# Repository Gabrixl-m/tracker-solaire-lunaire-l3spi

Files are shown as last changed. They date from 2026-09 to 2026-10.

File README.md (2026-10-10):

# Tracker solaire lunaire deux axes — maquette 3D à l'échelle 1:1

Maquette CAO d'un tracker solaire destiné à la surface de la Lune. Elle comprend :
* un trépied déployable ;
* une **tête rotative à vis sans fin** (azimut + élévation, deux petits moteurs pas à pas
  pilotés par un ESP32) ;
* **le panneau photovoltaïque de 356 × 253 × 30 mm**, avec son **capteur solaire** (4
  photodiodes sous une croix d'ombre, § 3) ;
* un faisceau de câbles et une unité de contrôle posée au sol.

Les deux vis sans fin sont **irréversibles** : la tête tient le panneau dans toutes les
positions **moteurs coupés**, sans contrepoids, sur Terre comme sur la Lune.
Toutes les cotes sont en **millimètres, à taille réelle**.

| Vue d'ensemble (panneau à 40°) | Tête rotative à vis sans fin |
|---|---|
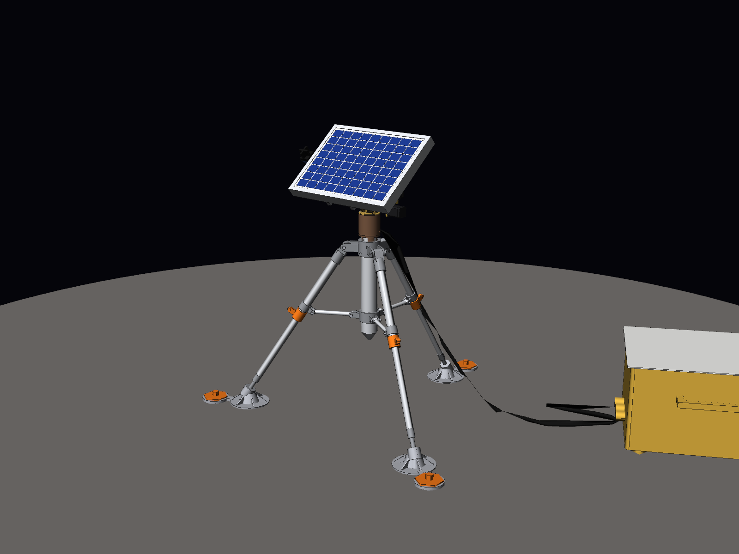
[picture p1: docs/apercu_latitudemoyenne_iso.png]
Vue d'ensemble
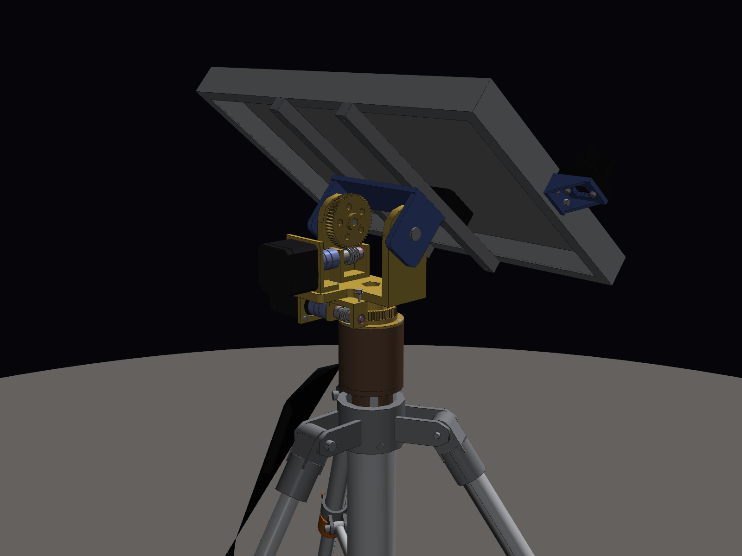
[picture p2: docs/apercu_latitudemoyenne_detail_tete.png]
Tête à vis sans fin
|  |  |
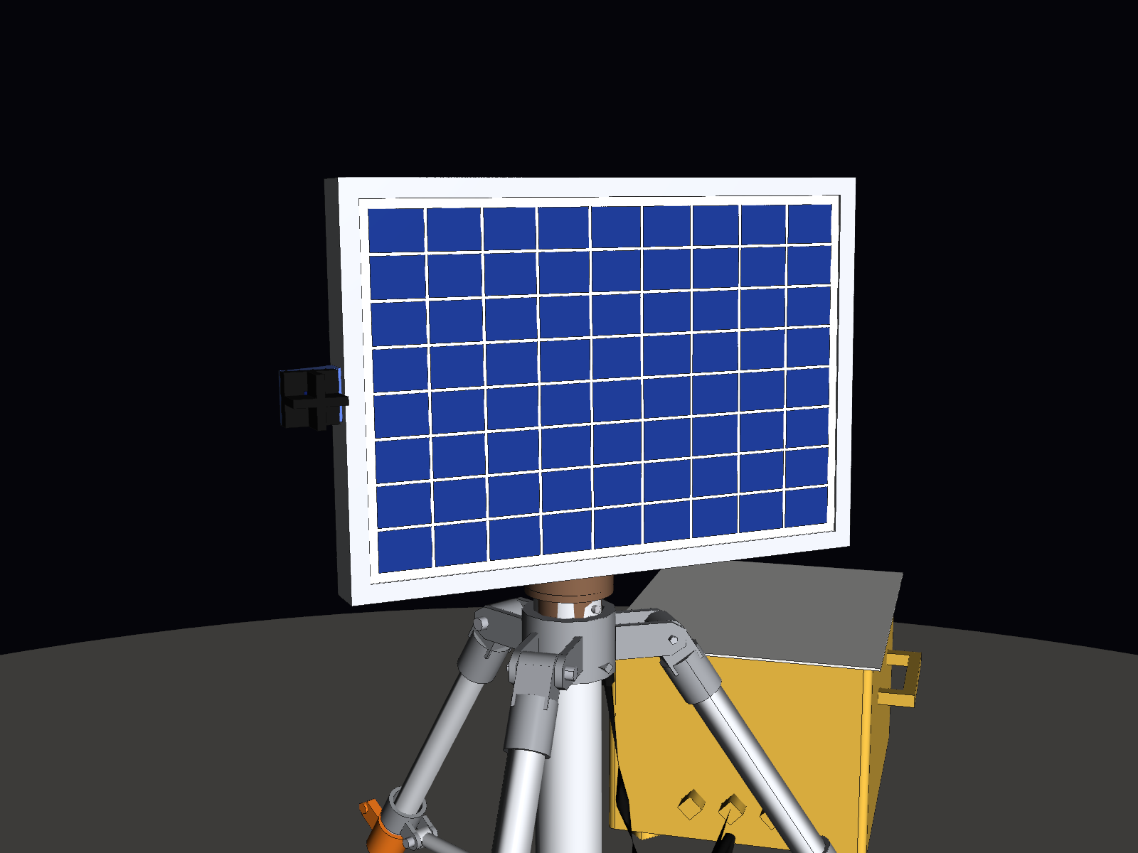
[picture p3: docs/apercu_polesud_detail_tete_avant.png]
Pôle Sud
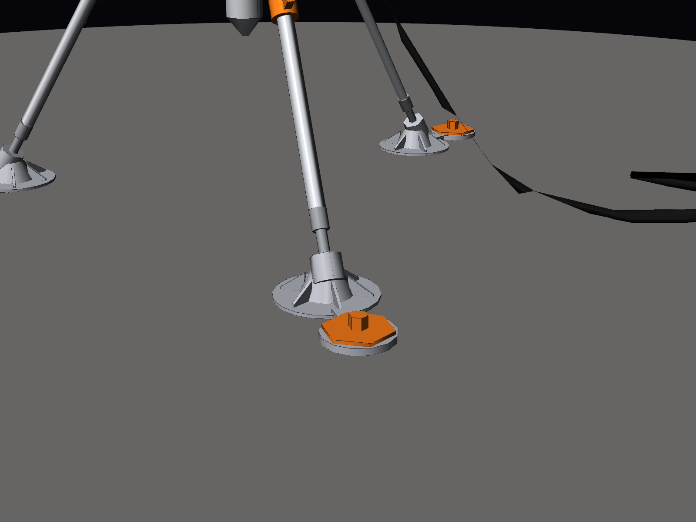
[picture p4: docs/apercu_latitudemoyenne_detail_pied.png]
Pied et vis d'ancrage
|  |  |

Ce document a trois parties, suivies de la bibliographie :
* **Partie A — Le tracker lunaire (cas réel)** : tête rotative, panneau, capteur solaire,
  conditions lunaires, trépied, matériaux et vérifications (§ 1 à 10) ;
* **Partie B — La démonstration sur Terre** : la même tête imprimée en PETG et posée sur un
  trépied photo, avec ce qui change par rapport au cas réel et tout ce qu'il faut pour la
  fabriquer (§ 11 à 19) ;
* **Partie C — Fichiers, scripts, régénération et licence** (§ 20 à 23) ;
* **Bibliographie**.

Organisation du dépôt :

```
CAO/Cas_Reel/          fichiers STEP du tracker lunaire : assemblages et pièces seules
CAO/Demo_Terre_PETG/   démonstration sur Terre : pièces à imprimer (STL + STEP) et assemblages
docs/                  rendus, images annotées, bilan de masse, optimisation des jambes
scripts/               scripts Python qui génèrent la CAO, les contrôles et les rendus
LISTE_ACHATS.md        liste d'achats de la démonstration sur Terre
requirements.txt       dépendances Python
LICENSE                licence CC BY-NC-SA 4.0
```

**Licence : [CC BY-NC-SA 4.0](LICENSE).** Libre pour un usage personnel, scolaire ou associatif,
en citant l'auteur ; **usage commercial interdit** ; les versions modifiées restent sous la
même licence (§ 23).

---

# Partie A — Le tracker lunaire (cas réel)

## 1. Tête rotative à vis sans fin

| Tête seule | Coupe : vis et roue d'élévation |
|---|---|
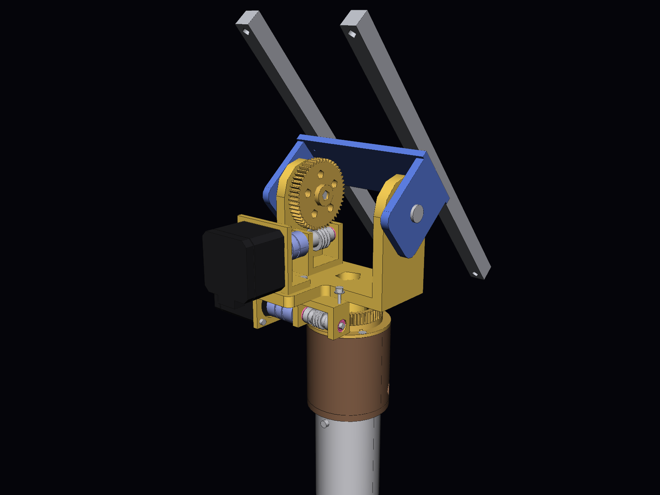
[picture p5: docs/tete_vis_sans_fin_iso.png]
Tête seule
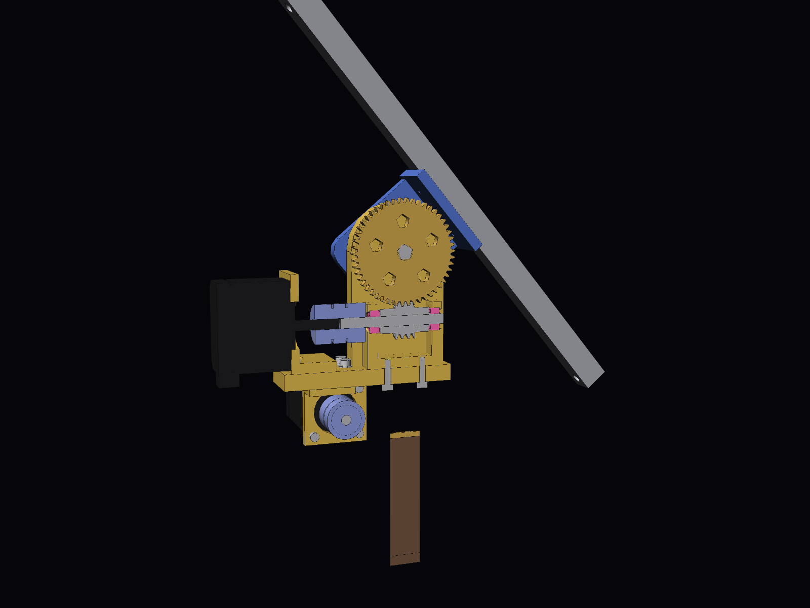
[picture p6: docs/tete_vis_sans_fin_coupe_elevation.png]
Coupe élévation
|  |  |
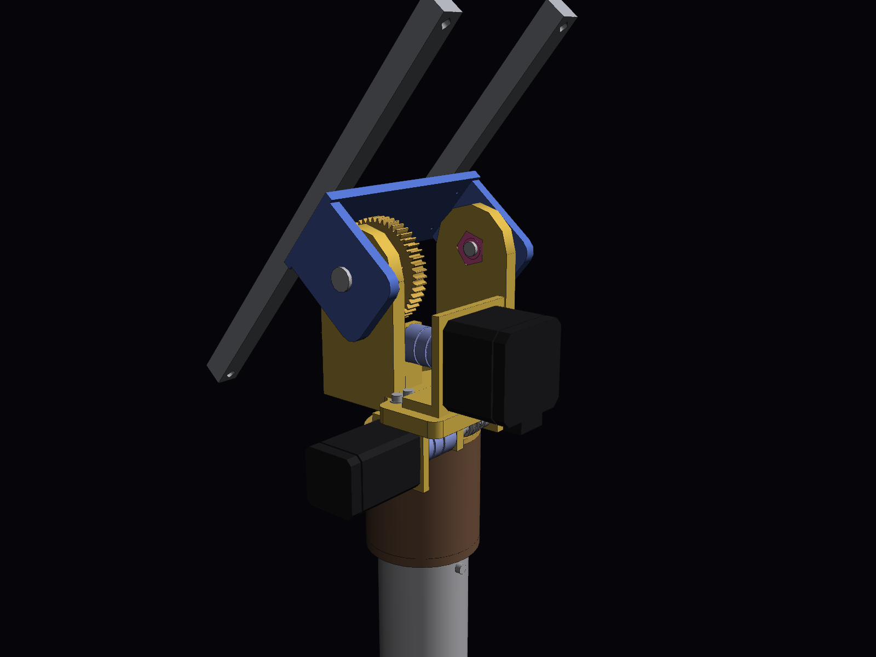
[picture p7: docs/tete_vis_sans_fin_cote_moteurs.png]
Côté moteurs
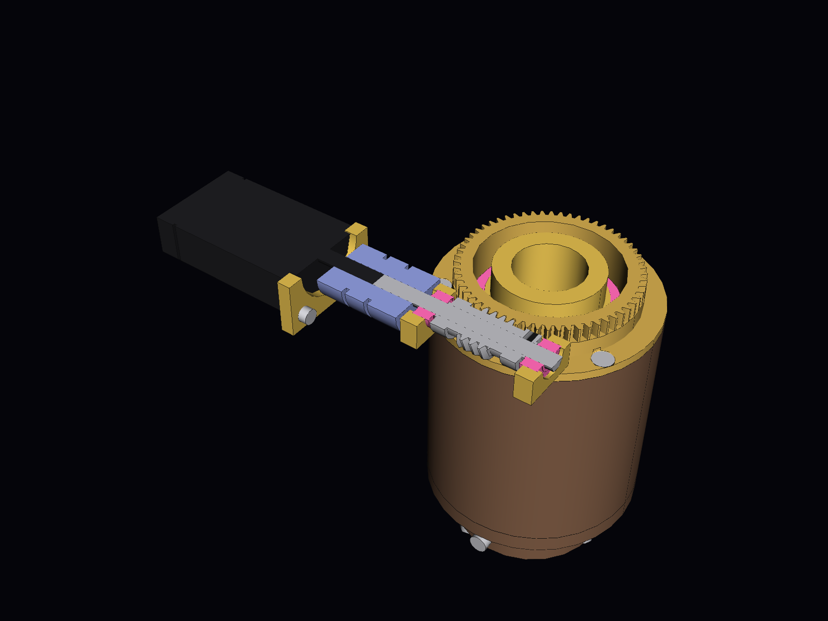
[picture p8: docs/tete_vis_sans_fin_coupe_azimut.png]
Coupe azimut
|  |  |
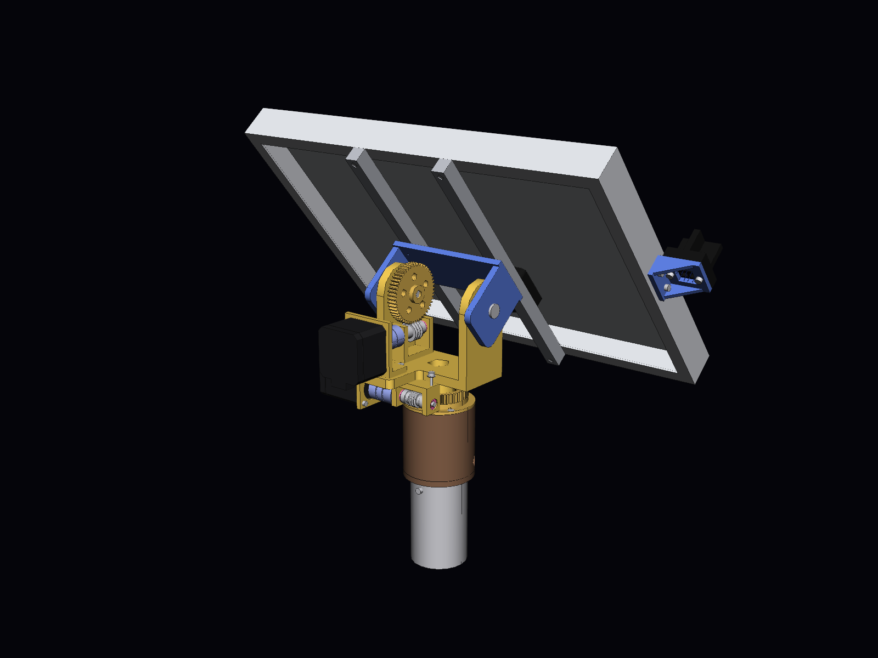
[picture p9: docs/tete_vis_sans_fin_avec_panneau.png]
Avec panneau, côté moteurs
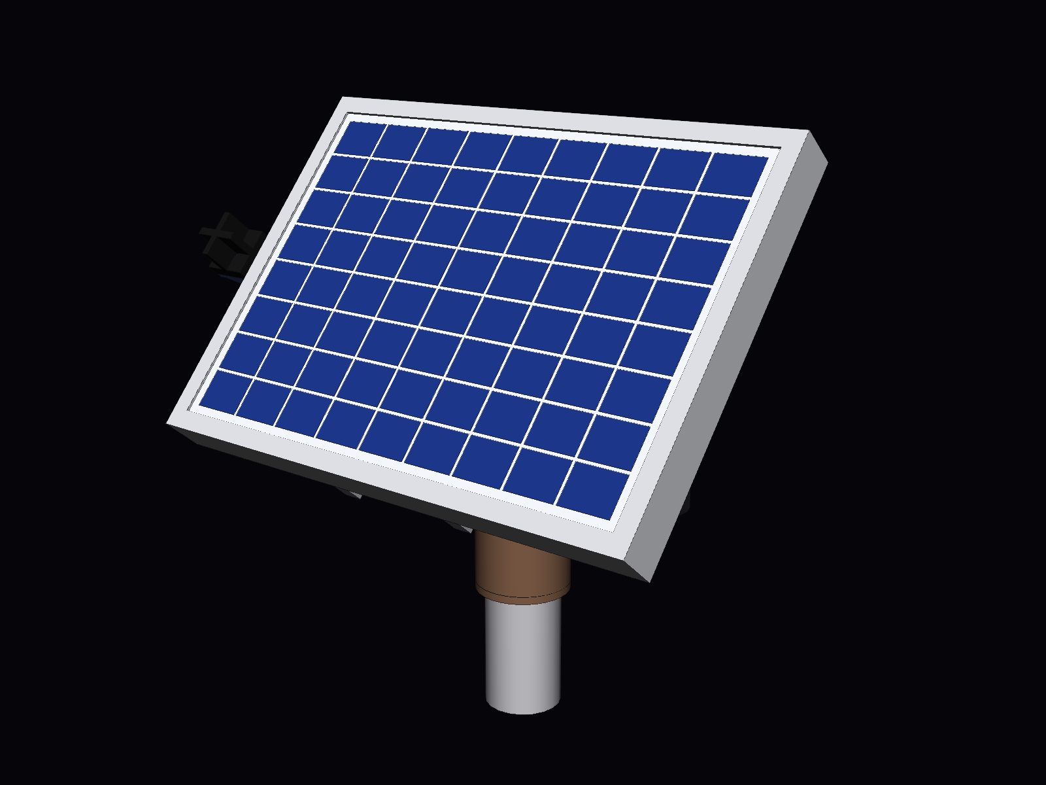
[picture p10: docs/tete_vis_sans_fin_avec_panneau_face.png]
Avec panneau, côté cellules
|  |  |

| Coupe par les axes (cas réel) : roulements en rose (6806 dans le socle, 608 dans les bras) |
|---|
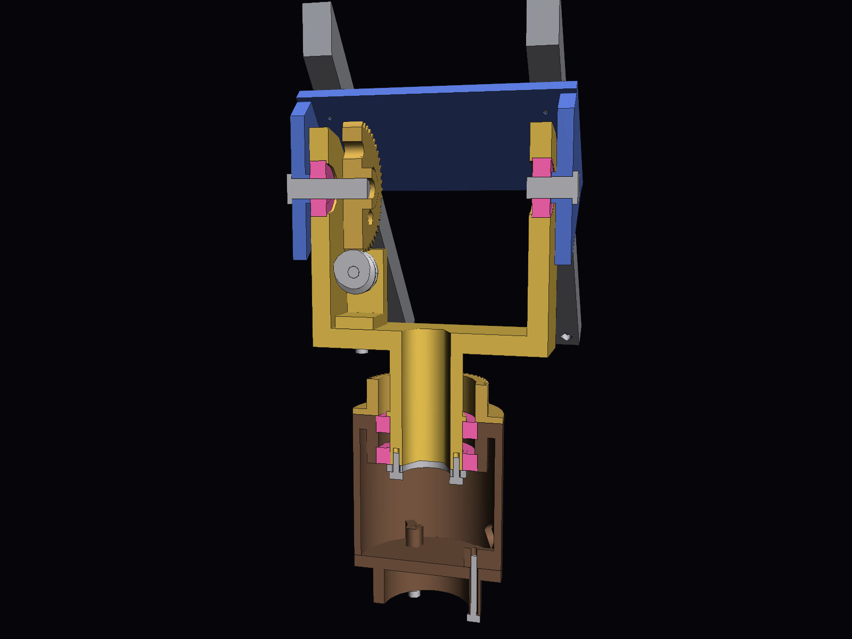
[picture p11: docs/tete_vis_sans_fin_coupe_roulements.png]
Coupe des roulements
|  |

### Architecture

La tête est un **mécanisme de pointage bi-axe azimut-élévation (AE)** : un axe vertical pour
tourner (azimut), un axe horizontal porté par lui pour incliner (élévation), et une fourche
(la chape) qui porte le panneau. Le choix de ce schéma est expliqué dans la bibliographie,
à la fin, avec l'article qui l'a guidé.

| Élément | Choix |
|---|---|
| **Socle** (brun) | Cylindre Ø62 posé sur la colonne du trépied, centré dedans par le fond et bloqué en rotation par une vis M3 radiale à travers la colonne. Il porte deux **roulements 6806** (Ø30/Ø42 × 7) et la **roue d'azimut, fixe**, posée à plat sur le socle et tenue par 3 vis M3 fraisées affleurantes, sous le passage de la vis d'azimut. Un passe-câble est orienté vers l'unité au sol |
| **Chape en U** (jaune) | Tourne en azimut sur les deux 6806. Sa plaque porte les **deux moteurs** et les deux vis. Ses bras portent les roulements de l'axe d'élévation (608), à 156 mm au-dessus de la colonne (700 mm du sol) |
| **Chapeau en U renversé** (bleu) | Coiffe la chape. Il pivote sur deux pivots dans les roulements des bras et porte les deux rails du panneau. Axes inox Ø8 sur roulements 608. Un **bossage** sur chaque flanc appuie sur la bague intérieure du roulement et règle le jeu axial |
| **Azimut (axe Y)** | **NEMA 11 de 45 mm** + vis sans fin m0,8 Ø12 sur la **roue bronze Z60 fixée sur le socle** : **60:1**. La vis roule autour de la roue, comme sur une tourelle. Le moteur tourne donc avec le panneau et ne se trouve jamais sur son chemin |
| **Élévation (axe X)** | **NEMA 17 de 34 mm** + vis sans fin m1 Ø16 sur la **roue bronze Z50** calée sur le pivot gauche du chapeau : **50:1**. Le moteur est à l'arrière de la chape, du côté opposé au panneau |
| **Vis** | Chaque vis tourne sur son arbre Ø5, porté par deux roulements 685. Ses deux moyeux appuient sur les bagues intérieures des 685, et une **lèvre** de chaque joue du palier retient leur bague extérieure : la poussée axiale de la vis va au palier. Un accouplement flexible la relie au moteur, si bien que le moteur ne reçoit pas cette poussée |
| **Liaison au panneau** | Deux rails 12 × 13 vissés sur le dessus du chapeau (4 × M3, par-dessus) et sur l'aile arrière du cadre (4 × M3 par-dessous, écrous dans le cadre). Le dos du cadre est à 46 mm de l'axe d'élévation |
| **Passage des câbles** | Les câbles descendent par le moyeu creux de la chape, font une boucle dans le socle et sortent par le passe-câble |
| **Fixations** | Vis CHC M3 (M2,5 pour le NEMA 11), toutes modélisées. Chaque tête de vis est accessible, et aucune n'est sur le passage d'une pièce mobile. Le palier et le support du moteur d'azimut sont vissés à travers des **lumières** de la chape, avec une rondelle sous chaque tête : on règle l'engrènement de la vis d'azimut en les faisant glisser |

### Roulements (en rose dans les fichiers 3D et les aperçus)

Tous les roulements sont **protégés** des deux côtés par des flasques métalliques (**ZZ**).
Leurs cotes sont celles des roulements ouverts, sauf pour le 685. Dans les fichiers 3D, la
protection est l'anneau en retrait de 0,2 mm sur chaque face.

| Réf. | Dimensions (Ø int. × Ø ext. × largeur) | Qté | Emplacement |
|---|---|---|---|
| **6806** (ISO 61806) | 30 × 42 × 7 mm | 2 | Azimut : dans le socle, autour du moyeu de la chape |
| **608** | 8 × 22 × 7 mm | 2 | Élévation : dans les bras de la chape, sur les axes Ø8 du chapeau |
| **685ZZ** | 5 × 11 × 5 mm | 4 | Arbres des deux vis sans fin, deux par vis, dans les paliers. Le 685 ouvert ne fait que 3 mm de large : il faut la version protégée |

**Aucune pièce ne touche la protection.** Une pièce qui tourne avec l'arbre n'appuie que sur la
bague intérieure, et une pièce fixe que sur la bague extérieure. Sinon, une pièce frotterait
sur la flasque, ou bien une pièce fixe freinerait la bague qui tourne.

| Roulement | Appui sur la bague intérieure (Ø maxi) | Appui sur la bague extérieure (Ø mini) |
|---|---|---|
| 6806 (azimut) | Collerette du moyeu et rondelle d'arrêt : **Ø33** | Épaulement du socle entre les deux roulements, et dessous de la roue d'azimut : alésage **Ø40** |
| 608 (élévation) | Bossage de chaque flanc du chapeau : **Ø11,5**, à 0,1 mm de la bague | Épaulement du bras de la chape : alésage **Ø19,8** |
| 685 (vis) | Épaulement de chaque moyeu de la vis : **Ø6,5**, à 0,15 mm de la bague | Lèvre de 1 mm de chaque joue du palier : alésage **Ø9,8** |

`scripts/generate_tete_vis_sans_fin.py` le vérifie à chaque génération, pour le cas réel et
pour la démonstration. Il contrôle les deux faces de chaque roulement : rien à moins de
0,3 mm de la protection, et chaque bague n'est approchée que par ce qui tourne avec elle.

Sur la Lune, les roulements sont en **acier 440C**, en version **ZZ** : les flasques
métalliques arrêtent la poussière de régolithe sans frotter. La lubrification est sèche
(MoS₂) : ni joint caoutchouc ni graisse, qui dégazeraient dans le vide.

**Pourquoi une vis sans fin.** Sans contrepoids, le panneau est forcément décentré : il doit
passer devant la chape pour devenir vertical. Son poids crée donc un couple sur l'axe
d'élévation, jusqu'à 0,95 N·m sur Terre. La vis sans fin est **irréversible** :
* le moteur fait tourner la roue ;
* la roue ne peut pas faire tourner la vis, parce que la pente du filet (3,6°) est plus
  faible que l'angle de frottement (environ 6°). C'est le principe du cric de voiture à vis.

Le panneau tient donc seul dans toutes les positions, même dans le vent et même en cas de
coupure de courant. Les moteurs ne sont alimentés que pendant les mouvements.

### Moteurs

| Axe | Moteur | Caractéristiques |
|---|---|---|
| Élévation | **NEMA 17, 42 × 42 × 34 mm** (type 17HS3401) | 0,34 N·m, 1,0 A, axe Ø5 × 23,5 à méplat, ≈ 0,22 kg |
| Azimut | **NEMA 11, 28 × 28 × 45 mm** (type 11HS18-0674S) | 0,10 N·m (0,095 retenu dans les calculs, par prudence), 0,67 A, 6,8 Ω, 0,18 kg, axe Ø5 × 20 à méplat |

Ce sont des moteurs du commerce : ils donnent la taille et le couple de référence. Pour le
vol, il faut leur équivalent en version vide ou spatiale, de même taille (§ 10).

### Couples : besoins et marges dans tous les cas

Les besoins sont calculés par `scripts/generate_tete_vis_sans_fin.py` à partir de la CAO :
* partie basculante (chapeau, roue, rails, panneau, capteur solaire) : 1,73 kg, dont 1,16 kg
  de panneau (pesé) et 0,06 kg de capteur solaire ;
* centre de gravité à 55,7 mm de l'axe, puisqu'il n'y a pas de contrepoids ;
* couple de gravité maximal (panneau vertical) : 0,95 N·m sur Terre et 0,16 N·m sur la Lune ;
* frottements : 0,01 N·m en élévation et 0,02 N·m en azimut ;
* vent de 10 m/s (36 km/h), pour les essais sur Terre en extérieur. La pression dynamique
  vaut 60 Pa, soit environ 6,5 N sur le panneau. Le centre de poussée est décalé de 5 à 8 cm
  en vent oblique, ce qui donne **+0,35 N·m en élévation et 0,50 N·m en azimut**.

Le couple disponible vaut couple de maintien × 0,7 (couple en marche lente en micro-pas) ×
rapport × rendement de la vis. Le rendement d'une vis à un filet vaut 0,29 (élévation) et
0,30 (azimut), avec un frottement prudent μ = 0,15.

| Marge = disponible / besoin | Lune | Terre, intérieur | Terre, extérieur (vent 10 m/s) |
|---|---|---|---|
| Élévation (3,47 N·m disponibles, moteur à 1,0 A) | ×21 | ×3,6 | **×2,7** |
| Azimut (1,22 N·m disponibles) | ×61 | ×41 | **×2,3** |

* **Le cas qui dimensionne est l'essai sur Terre, en extérieur.** On y vise une marge
  d'environ 2, sans surdimensionner. Les grandes marges sur la Lune viennent de l'absence de
  vent et de la gravité six fois plus faible : le même matériel doit aussi être essayé à 1 g.
* **Chaque moteur est le plus petit moteur courant qui convient.** Avec le moteur juste en
  dessous, la marge en vent devient insuffisante :
  * élévation : NEMA 11 de 45 mm, ×0,77 ;
  * azimut : NEMA 11 court (32 mm, ≈ 0,05 N·m), ×1,2.

### Bilan de dimensionnement : est-ce surdimensionné ?

Calculé avec le panneau pesé (1,16 kg), les masses des pièces d'après leurs matériaux, le
rendement des vis, les roulements et les câbles.

| Ce qu'on regarde | Cas réel | Verdict |
|---|---|---|
| Part du couple moteur utilisée, élévation | 38 % dehors (vent 10 m/s), 5 % sur la Lune, à 1,0 A | Bien dimensionné dehors ; ×21 de trop sur la Lune |
| Part du couple moteur utilisée, azimut | 43 % dehors, 2 % sur la Lune | Dimensionné par le vent ; sans vent, ×40 à ×60 de trop |
| Roulements | En marche : poussée de la vis ≈ 1/5 de la capacité statique d'un 685 ; charge ≈ 1/100 de celle d'un 6806 | Choisis pour leurs dimensions (câbles, axes), pas pour la charge |
| Inertie | ≈ 0,012 kg·m² basculants : < 1 % du couple de gravité même en retour rapide | Négligeable |

* **Dehors, les marges sont de ×2,7 (élévation) et ×2,3 (azimut).** Pour un moteur pas à pas,
  on vise ×1,5 à ×2 : au-delà de son couple, il ne ralentit pas, il **saute des pas** et perd
  sa position. Le couple réel varie aussi de 10 à 20 % selon le vendeur et la température.
* **Les grandes marges (intérieur, Lune) ne coûtent rien.** Le même matériel doit tenir le
  pire cas. Un moteur plus petit ne tiendrait pas le vent (voir ci-dessus). Pour une
  version de vol seulement, sans essais à 1 g, un NEMA 8 long (≈ 0,04 N·m) suffirait en
  élévation sur la Lune : il n'y faut que 0,011 N·m au moteur.
* **Vitesse** : le Soleil avance de 15°/h en moyenne sur Terre (jusqu'à ≈ 40°/h en azimut
  vers midi en été) et de 0,5°/h sur la Lune. Sur Terre, le moteur d'azimut fait donc de
  2,5 à environ 7 tours par heure, et celui d'élévation au plus 2,1. À cette vitesse, un
  pas à pas donne tout son couple, et la puissance mécanique à l'axe est de l'ordre de
  0,1 mW.
* **Pertes** : chaque vis perd 70 % du couple moteur en frottement (rendement 0,29 à
  0,30). C'est le prix de l'irréversibilité : la vis sert de frein, sans frein à acheter ni
  courant de maintien. Les roulements et les câbles ne coûtent que 0,01 à 0,02 N·m, soit 1 à
  4 % du besoin.
* **Énergie** : alimentés, les moteurs consomment environ 5,5 W (NEMA 17 à 1,0 A) et 6 W
  (NEMA 11). Comme les vis tiennent seules, les drivers sont coupés entre deux corrections.
  Avec une correction de 0,5° toutes les 2 minutes, les moteurs sont alimentés moins de 1 %
  du temps, soit quelques dizaines de mW en moyenne au lieu de 12 W.

### Tenue moteurs coupés

| Cas | Ce qui tient | Résultat |
|---|---|---|
| **Terre**, vis graissées (μ ≈ 0,10) | La vis se bloque : hélice de 3,6° (élévation) et 3,8° (azimut), angle de frottement 5,7° | **Tient dans toutes les positions, même dans le vent** |
| Terre, frottement réduit par des vibrations (μ ≈ 0,05) | La vis peut redevenir réversible. Le couple résiduel du moteur coupé (valeurs typiques : 0,016 N·m pour le NEMA 17, 0,005 N·m pour le NEMA 11) prend le relais | Tient : ×3,1 en élévation, ×2,4 en azimut |
| **Lune**, MoS₂ sous vide (μ ≈ 0,02) | La vis est réversible, mais la gravité ne donne que 0,16 N·m et il n'y a pas de vent | **Tient** : ×7,5 en élévation par le couple résiduel du moteur. En azimut, rien ne pousse |

Conséquences :
* **Aucun courant à l'arrêt** : drivers désactivés entre deux mouvements, donc consommation
  nulle. Le suivi consomme moins de 0,5 Wh par jour, ce qui compte pour la nuit lunaire de
  14 jours.
* **Pas de surchauffe dans le vide**, puisque les moteurs sont presque toujours coupés.
* **La position n'est pas perdue** : au réveil, le moteur bouge au plus d'un pas, soit
  0,036° au panneau.
* **Ne jamais forcer le panneau à la main** : on forcerait directement sur les dents de la
  roue en bronze. Pour le bouger, alimenter le moteur ou tourner l'arbre de la vis.

### Limites de vent (sur Terre)

| | Limite |
|---|---|
| Tourner sans perdre de pas | environ 24 m/s en élévation, **environ 15 m/s (55 km/h) en azimut** |
| Tenir moteurs coupés | environ 30 m/s : au-delà, ce sont les dents de bronze qui limitent |
| **Trépied non ancré** (pire orientation) | **basculement vers 16 m/s (58 km/h)** |

Au-delà d'environ 15 m/s, c'est le trépied qui limite. Pour un essai en extérieur,
planter les vis d'ancrage ou lester les pieds. Au-dessus de 10 m/s, mettre le panneau à plat
(élévation 90°), où le vent a le moins de prise, puis couper les moteurs.

### Résolution et vitesses (moteurs à 200 pas/tour, 1/16 de pas)

| | Élévation | Azimut |
|---|---|---|
| Pas entier au panneau | 0,036° | 0,030° |
| Micro-pas (1/16) | 0,0023° | 0,0019° |
| Vitesse conseillée | 14°/s (moteur à 120 tr/min) | 12°/s |

Le Soleil se déplace d'environ 0,5°/h sur la Lune et 15°/h sur Terre : un retour à plat ou
une remise en position prend quelques secondes.

**Plages de mouvement** :
* élévation de −2° à +92° (butées). Le panneau peut ainsi passer à la verticale au lever et
  au coucher du Soleil, et en permanence au pôle Sud ;
* azimut limité à ±180° par la boucle de câble, puis retour en arrière. Au pôle Sud, il faut
  un tour complet par jour lunaire : on revient en arrière une fois par jour, ou l'on monte
  un collecteur tournant dans le moyeu.

### Commande

* **Électronique** : un ESP32 et deux drivers **TMC2209** (16 micro-pas, StealthChop), dans
  l'unité de contrôle au sol, avec la batterie. Pour le vol, il faudrait leurs équivalents
  résistants aux rayonnements.
* **Courants de marche** : 1,0 A pour le NEMA 17, 0,67 A pour le NEMA 11.
* **À l'arrêt, les drivers sont coupés** : les vis tiennent seules, donc ni courant ni
  échauffement entre deux mouvements.
* **Origines** :
  * un micro-switch en butée basse d'élévation (−2°) ;
  * un capteur à effet Hall et un aimant sur la roue fixe pour l'azimut.

  La détection de calage sans capteur (StallGuard) n'est pas fiable à basse vitesse,
  surtout derrière une vis sans fin.
* **Suivi du Soleil** : capteur solaire et calcul de la position du Soleil (§ 3).

Le câblage détaillé (broches, réglages, bibliothèques) est celui de la démonstration, au § 16.

## 2. Panneau photovoltaïque

* **356 × 253 × 30 mm** : cadre aluminium en C (rebord avant et aile arrière de 12 mm),
  laminé verre 3,2 mm + EVA + face arrière, 72 cellules (9 × 8), boîte de jonction au dos.
* Monté en **format paysage** : l'axe d'élévation est parallèle au côté de 356 mm.
* **Masse : 1,16 kg (pesée)**. Le modèle en tient compte (`P["pan_masse"]` dans
  `scripts/generate_tracker.py`) : couples, stabilité et angle des jambes sont calculés avec.
* **Fixation** : 4 vis M3×14 par-dessous traversent les bouts des rails (têtes noyées) et
  l'aile arrière du cadre, avec un écrou M3 posé dans le cadre. Il faut percer 4 trous Ø3,4
  dans l'aile arrière des grands côtés : à 44 mm de part et d'autre du milieu, à 6 mm du bord
  extérieur. Vérifier que l'aile arrière du vrai cadre fait au moins 10 mm.
* **Capteur solaire** sur le petit côté du pivot libre (§ 3) : percer 2 trous Ø3,4 dans ce
  petit côté, à 9 mm de part et d'autre du milieu et à 12 mm du dos du cadre.
* Le dos du cadre est à **46 mm de l'axe d'élévation**. Ce décalage permet au panneau de
  passer à la verticale devant la chape. Son point le plus bas (≈ 571 mm du sol, à −2°)
  passe à côté du socle et de la roue d'azimut, et reste au-dessus de tout le trépied.
* Les coins en plastique noir visibles sur la photo du panneau sont des protections
  d'emballage. Ils ne sont pas modélisés.

## 3. Capteur solaire et suivi du Soleil

| Le capteur sur le petit côté du cadre | Coupe par deux photodiodes |
|---|---|
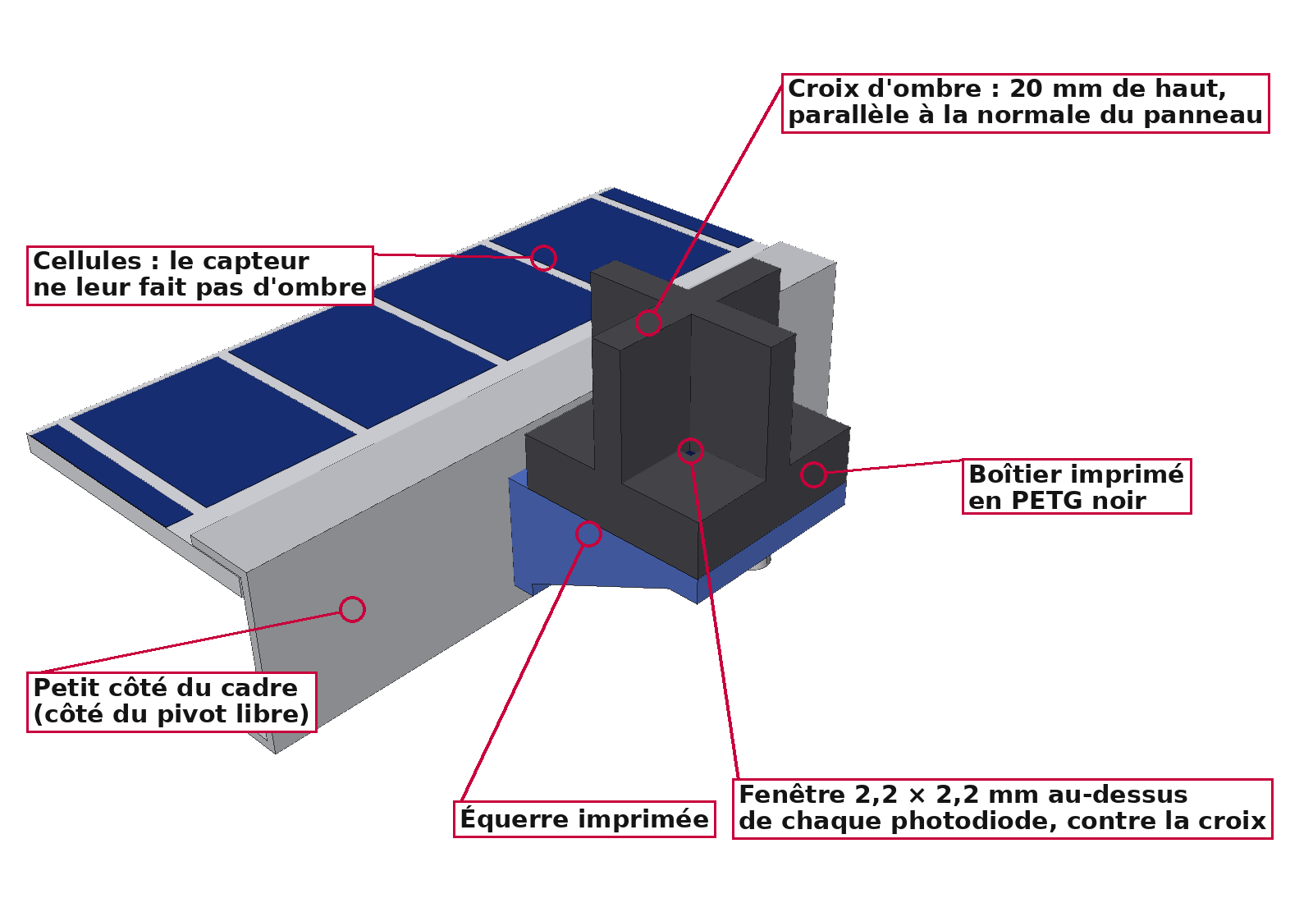
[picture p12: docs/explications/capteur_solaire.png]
Capteur solaire
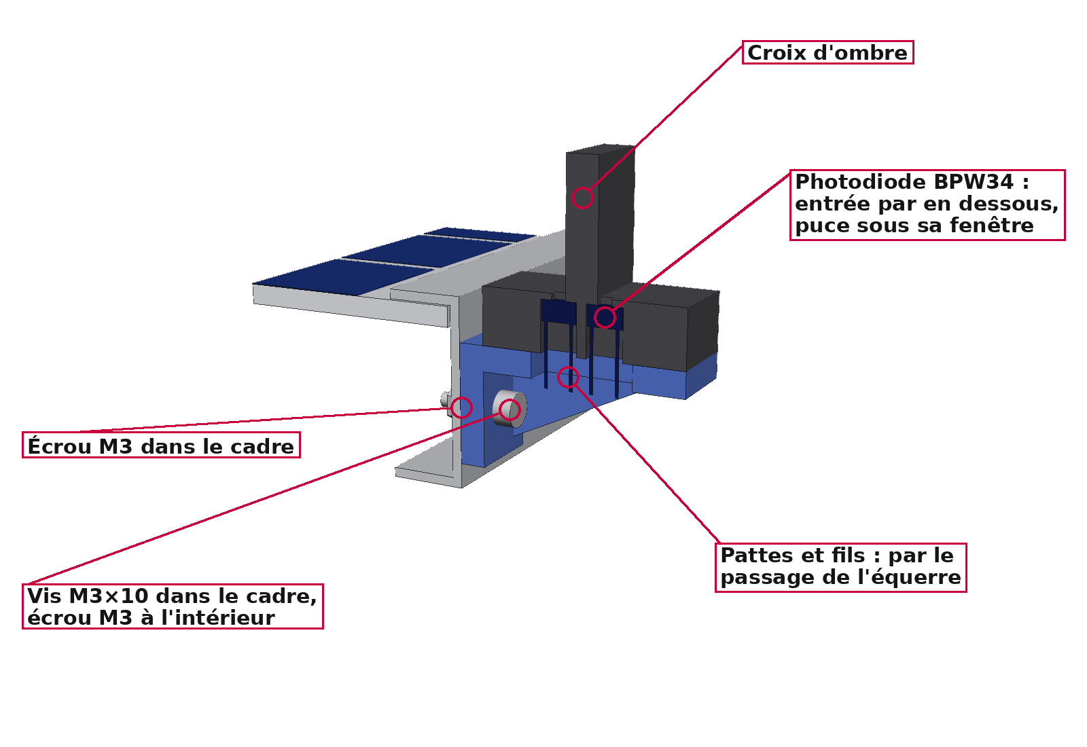
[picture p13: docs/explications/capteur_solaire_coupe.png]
Coupe du capteur solaire
|  |  |

### Principe : 4 photodiodes et une croix d'ombre

Quatre photodiodes **BPW34** sont placées aux quatre coins d'une **croix opaque de 20 mm de
haut**, parallèle à la normale du panneau.
* Quand le panneau vise exactement le Soleil, la croix ne fait d'ombre sur aucune
  photodiode : les quatre reçoivent la même lumière.
* Dès qu'il s'en écarte, l'ombre d'un mur de la croix couvre une partie des deux photodiodes
  du côté opposé au Soleil : 0,37 mm d'ombre pour 1° d'écart.
* Chaque photodiode voit le ciel par une **fenêtre de 2,2 × 2,2 mm**, un peu plus petite
  que sa puce (environ 2,7 mm de côté). Le bord intérieur de la fenêtre prolonge la face
  du mur : l'ombre mord sur la fenêtre dès le moindre écart. Il n'y a **pas de zone
  morte** autour du pointage parfait.
* **Réponse** : le rapport des signaux (plus bas) varie d'environ **9 % par degré**, de façon
  linéaire jusqu'à ±6°. Au-delà, il sature mais garde son signe : tant que le Soleil est
  devant le panneau, le capteur indique dans quel sens tourner.

Les photodiodes sont repérées **HG, HD, BG, BD** :
* **haut / bas** (H, B) le long du côté de 253 mm, celui qui bascule en élévation. Le
  « haut » est le côté du bord supérieur du panneau quand il est incliné ;
* **gauche / droite** (G, D) le long du côté de 356 mm, parallèle à l'axe d'élévation.

### Montage sur le cadre

* Le capteur est au milieu du **petit côté du cadre, côté du pivot libre**, à l'opposé de la
  roue d'élévation. Il tourne avec le panneau et mesure donc l'erreur du panneau lui-même.
* Il est **à côté des cellules**, pas au-dessus. Pour qu'il leur fasse de l'ombre, il faudrait
  que le Soleil soit à plus de 40° de l'axe du panneau, ce qui n'arrive pas en suivi.
* Les photodiodes sont 1 mm au-dessus du rebord avant du cadre : le cadre ne leur fait pas
  d'ombre non plus.
* L'**équerre** se visse contre le petit côté avec 2 vis M3×10. Leurs écrous M3 sont
  posés à l'intérieur du cadre, sous le laminé, et on les atteint par le dos ouvert du panneau,
  comme ceux des rails. Il faut percer 2 trous Ø3,4 dans le petit côté : à 9 mm de part et
  d'autre du milieu et à 12 mm du dos du cadre.
* Le **boîtier** se visse sur l'équerre par-dessous (2 vis M3×10 dans des avant-trous).
* La croix est alors parallèle à la normale du panneau, à l'impression près. Inutile de
  régler plus finement : un défaut de 1° ne coûte que 0,015 % de puissance (plus bas).

### Ce que fait le programme

```
H = HG + HD    B = BG + BD    G = HG + BG    D = HD + BD    S = H + B
erreur d'élévation = (H − B) / S      environ 0,087 par degré
erreur d'azimut    = (G − D) / S
```

* Les rapports ne dépendent pas de la force du Soleil. Un voile léger ou une poussière
  uniforme sur le capteur ne déplacent pas leur zéro.
* **Étalonnage, une seule fois** : poser une feuille de papier calque sur la croix, au soleil.
  Les 4 photodiodes reçoivent alors la même lumière. Noter les 4 valeurs, et en déduire un
  coefficient par photodiode (moyenne des 4 / sa valeur), pour corriger leurs petites
  différences.
* Si S est trop faible (nuage, nuit), ignorer le capteur et rester sur la position calculée.
* Si l'erreur est sous 0,026 (≈ 0,3°), ne pas bouger, pour que le panneau n'oscille pas.
* En azimut, diviser l'erreur par cos(élévation) avant de la convertir en pas : près du
  zénith, l'azimut doit beaucoup tourner pour corriger une petite erreur (voir la
  bibliographie).
* Au premier essai, vérifier le **sens** de chaque correction et l'inverser dans le programme
  s'il le faut. Le sens dépend du câblage, et du sens dans lequel le boîtier est vissé.

Il n'est pas utile de viser plus juste : une erreur de 1° ne fait perdre que 0,015 % de la
puissance du panneau, et 5° seulement 0,4 %.

### Stratégie de suivi sur la Lune : les photodiodes en principal, le calcul en secours

* **Il n'y a pas de GPS sur la Lune**, et le trépied posé par un astronaute n'est ni orienté
  ni parfaitement de niveau. Les photodiodes ne dépendent de rien de tout cela : elles mesurent
  directement l'écart entre le panneau et le Soleil. Ce sont elles qui pilotent.
* **Le calcul théorique sert de redondance.** Il n'a pas besoin de GPS :
  * la position du site d'atterrissage est connue de la mission ;
  * l'heure vient de l'horloge de bord ;
  * avec les éphémérides de la Lune, l'ESP32 en déduit la direction du Soleil ;
  * l'inclinaison du trépied se mesure avec un accéléromètre, qui marche aussi en gravité
    lunaire ;
  * l'orientation vers le nord est apprise au premier pointage. L'ESP32 fait tourner la tête
    en azimut jusqu'à ce que les photodiodes voient le Soleil, puis le centre ; l'écart avec
    l'azimut calculé donne le nord.
* **À quoi sert ce secours** :
  * reprendre le Soleil à l'aube, après les 14 jours de la nuit lunaire, ou après le passage
    d'une ombre. Le calcul pointe le panneau au bon endroit, puis le capteur prend le relais ;
  * continuer si une photodiode tombe en panne ou se couvre de poussière d'un seul côté.
    L'ESP32 compare en permanence les deux. S'ils restent en désaccord de plus de 1 à 2°, il
    suit le calcul et signale le défaut.
* Comme une erreur de quelques degrés ne coûte presque rien en énergie (plus haut), le
  calcul seul suffit à alimenter le système le temps d'une panne du capteur.

Pour une version de vol, le capteur serait en aluminium anodisé noir (c'est déjà le
matériau du cas réel dans la CAO), avec une **fenêtre en silice fondue** contre la poussière
de régolithe, et des photodiodes qualifiées pour le spatial (rayonnements, −173 à +127 °C).
La BPW34, utilisée pour la démonstration (§ 17), est un composant du commerce.

## 4. Conditions lunaires et réponses de conception

| Contrainte lunaire | Conséquence sur le tracker |
|---|---|
| **Gravité 1,62 m/s² (1/6 g)**, **pas de vent** | Charges très faibles sur la tête et le trépied. Le couple dû au décentrage du panneau autour de l'axe d'élévation est six fois plus faible que sur Terre. Les essais au sol à 1 g, avec du vent, restent le cas le plus exigeant pour les moteurs. |
| **Vide** | **Soudage à froid** : chaque contact associe deux matériaux différents (vis en inox 17-4PH contre roues en bronze, roulements en acier 440C), avec une lubrification sèche au MoS₂. **Pas de convection** : les moteurs ne sont alimentés que pendant les mouvements, grâce aux vis irréversibles, et leur chaleur part par conduction vers la chape. Il faut des moteurs en version « vide » (graisses et isolants à faible dégazage), de même taille. |
| **Températures de −173 °C à +127 °C** | Jeu de denture de 0,1 mm. Jeu axial de 0,1 mm par côté entre les bossages du chapeau et les bagues intérieures des 608 : chapeau et chape sont dans le même alliage et se dilatent ensemble. Pas de plastique ordinaire dans la tête : le PLA d'un prototype imprimé en 3D se ramollit vers 60 °C. |
| **Régolithe abrasif et électrostatique** | Vis et roues à protéger par un soufflet ou un capot, connecteurs orientés vers le bas, câbles passés par l'axe d'azimut. |
| **Sol meuble et irrégulier** | Trépied à trois appuis, patins Ø120 à crampons sur rotule, jambes télescopiques, vis d'ancrage hélicoïdales (voir § 6). |
| **Jour lunaire de 29,5 jours terrestres, nuit de 14 jours** | Suivi très lent (≈ 0,5°/h), donc peu de pas moteur. Aucune consommation à l'arrêt grâce aux vis irréversibles. |

## 5. Choix de l'angle

Sur la Lune, l'axe de rotation n'est incliné que de **1,54°**. La hauteur du Soleil à midi
vaut donc presque exactement 90° moins la latitude du site :

* **Pôle Sud (programme Artemis)** : le Soleil reste à **±1,5° de l'horizon** et fait
  **un tour complet d'azimut par jour lunaire**. Le panneau est **quasi vertical** et
  l'azimut tourne en continu. C'est la pose du fichier principal.
* **Latitudes moyennes (sites Apollo, environ 20 à 26°N)** : le Soleil monte jusqu'à 64–70°.
  La pose fournie (Soleil à 50°) donne un panneau **incliné à 40°**.
* Au lever et au coucher du Soleil, **tout site** exige un panneau vertical, d'où la plage
  d'élévation de −2° à +92°.

## 6. Trépied

Le trépied est **dimensionné pour le panneau de 356 × 253 mm et la tête à vis sans fin**.
Architecture : trois jambes en Y à 120°, articulées sur un moyeu, avec entretoises vers un
collier inférieur coulissant, jambes télescopiques, patins sur rotule et ancrages.

### Angle φ des jambes : optimisé, **φ = 33,0°** (angle entre jambe et colonne)

L'articulation haute est fixée par le panneau : tout le trépied doit rester sous le volume
qu'il balaie. Elle est donc à 509 mm du sol, juste sous le socle de la tête. φ fixe alors
le rayon des pieds, la longueur des jambes et leur course télescopique.
`scripts/optimisation_angle.py` évalue chaque angle de 25° à 60° avec les masses et le
centre de gravité réels de la CAO, dans la pire orientation du panneau.

| Contrainte | Exigence | Effet de φ |
|---|---|---|
| **C1 Stabilité sans ancrage** | Tenir sur une pente de 15°, avec un caillou ou un enfoncement de 50 mm sous un pied, et 5° de marge | Plus φ est grand, plus les pieds sont écartés et plus le tracker est stable : **φ ≥ 33,0°** |
| **C2 Mise à niveau** | Les jambes télescopiques (deux tubes) remettent la tête de niveau sur une pente de 10° | Plus φ est grand, plus la course nécessaire croît vite : φ ≤ 52° |
| **C3 Garde au sol** | Pointe de la colonne à au moins 150 mm du sol | φ ≤ 49,4° |

Tous les autres critères se dégradent quand φ augmente : longueur et masse des jambes,
poussée reprise par les entretoises (le frottement au sol est six fois plus faible sur la
Lune), course de nivelage et emprise au sol. **L'optimum est donc le plus petit angle
admissible, 33,0°** (plage admissible : 33,0° à 49°). La rigidité latérale, maximale à 54,7°,
ne dimensionne pas sur la Lune, où il n'y a pas de vent.

La tête à vis sans fin est légère (tête + panneau : 3,0 kg, avec le panneau pesé à
1,16 kg) : le centre de gravité du tracker est bas, ce qui permet cet angle faible. Avec
le panneau estimé d'abord à 1,01 kg, l'optimum était 32,5° ; les 150 g de plus au sommet
l'ont fait passer à 33,0°.

L'optimum dépend des exigences. Par exemple, il passe à 38° pour une pente de 20° ou une
marge de 10°. Le détail est dans
[`docs/optimisation_angle_jambes.md`](docs/optimisation_angle_jambes.md). Si la masse
de la tête ou du panneau change, relancer `python scripts/optimisation_angle.py`.

### Dimensions qui en découlent

| Dimension | Ce qui l'a fixée |
|---|---|
| **Axe d'élévation à 700 mm** | Le point bas du panneau vertical doit rester nettement au-dessus du sol : il est à 571 mm. Plus haut, le tracker serait plus lourd et moins stable sans raison. |
| **Sommet de la colonne à 544 mm**, moyeu des jambes à 509 mm | La tête met l'axe d'élévation 156 mm au-dessus de la colonne. Tout le trépied reste sous le volume balayé par le panneau. |
| **Pieds sur un cercle de Ø749 mm**, jambes de 559 mm | Conséquence de φ = 33,0°. Basculement sans ancrage à 25,2° dans la pire orientation du panneau (exigé : 25,1°). |
| **Course télescopique ±79 mm**, bague de blocage | Remise à niveau sur une pente de 10°. Le tube inférieur Ø20 coulisse dans le tube supérieur Ø25 avec au moins 45 mm de recouvrement. |
| **Entretoises horizontales** Ø12 × 1, bride juste au-dessus de la bague | Meilleur bras de levier. Le collier inférieur se place à leur hauteur (304 mm). |
| **Tubes Ø25 × 1,5 et Ø20 × 1,5, colonne Ø50 × 2, axes Ø6 et Ø5** | Minimum pratique à cette échelle (manutention avec des gants de scaphandre, chocs). Ces sections ne sont pas calculées d'après le poids : à vérifier quand la masse sera figée. |
| **Patins Ø120 à crampons, rotule ±20°** | Pression sur le régolithe d'environ 340 Pa sur la Lune ; adaptation aux pentes et aux cailloux. |
| **Vis d'ancrage hélicoïdales Ø60, enfoncées de 400 mm** | Un piquet lisse tient par frottement, six fois plus faible que sur Terre. L'hélice s'appuie au contraire sur la couche compacte du régolithe, sous 30 cm. Les vis se posent avec une visseuse à travers l'anneau du patin. Sur Terre, elles servent aussi contre le vent (voir § 1, « Limites de vent »). |

Le trépied pèse 4,3 kg.

## 7. Matériaux

| Élément | Matériau (cas réel) |
|---|---|
| Socle, fond, chape, chapeau en U, paliers et supports de moteurs | Al 6061-T6 anodisé |
| Rondelle d'arrêt du moyeu | Inox 17-4PH |
| Roues des vis sans fin (azimut et élévation) | Bronze CuSn12 |
| Vis sans fin | Inox 17-4PH |
| Arbres des vis sans fin Ø5 | Inox 17-4PH |
| Pivots d'élévation | Inox 17-4PH, Ø8 (dont un en D), sur 608 |
| Accouplements | Al 7075-T73 |
| Roulements | 6806, 608, 685 **ZZ** en acier 440C, lubrification sèche (MoS₂) |
| Lubrification des vis et des roues | MoS₂ sec |
| Visserie | Inox ou titane |
| Moteurs | Version vide / spatiale (même taille) |
| Rails du panneau | Al 6061-T6 |
| Ferrures et colliers du trépied, axes, vis d'ancrage | Ti-6Al-4V |
| Tubes de jambes, colonne, entretoises, patins | Al 7075-T73 anodisé dur |
| Cadre du panneau | Al 6063-T5 |
| Capteur solaire : boîtier à croix et équerre | Al 6061-T6 anodisé noir, fenêtre en silice fondue, photodiodes qualifiées pour le spatial |

## 8. Caractéristiques principales

| Grandeur | Valeur |
|---|---|
| Hauteur de l'axe d'élévation | 700 mm |
| Angle des jambes | φ = 33,0° par rapport à la colonne (optimisé) |
| Emprise au sol | Pieds sur Ø749 mm, Ø869 mm hors patins (≈ Ø1050 mm avec les anneaux d'ancrage) |
| Panneau | 356 × 253 × 30 mm, 72 cellules |
| Puissance du panneau | ≈ 10 W crête sur Terre (valeur typique de ce format, à confirmer sur sa fiche) |
| Débattements | Azimut ±180° (boucle de câble), élévation −2° à +92° |
| Réductions | Azimut 60:1, élévation 50:1, vis sans fin irréversibles |
| Moteurs | NEMA 17 de 34 mm (élévation), NEMA 11 de 45 mm (azimut), pilotés par ESP32 + TMC2209 |
| Masse de la tête (partie fixe + partie tournante, hors panneau) | 1,86 kg, dont 0,40 kg de moteurs |
| Masse de la partie qui bascule (panneau + chapeau + roue + rails + capteur solaire) | 1,73 kg, dont 1,16 kg de panneau |
| Masse du trépied | 4,3 kg |
| Masse du tracker complet | 7,4 kg (poids lunaire ≈ 12 N) |

Le détail pièce par pièce est dans `docs/bilan_masse.csv`. Les moteurs et l'unité au sol ont
une **masse forfaitaire**, car leur intérieur n'est pas modélisé.

## 9. Vérifications effectuées par les scripts

* **Interférences pièce à pièce** dans les deux poses du tracker et dans la tête seule,
  en cotes réelles comme en version PETG, capteur solaire compris : **aucune**.
  * Toutes les vis sont modélisées, avec leur tête et leur noyau : chaque tête est
    accessible, et aucune vis ne dépasse de son trou ni ne touche une autre pièce.
  * **Prise de chaque vis** : le script suit chaque vis le long de son axe. Toutes mordent d'au
    moins 3,5 mm dans la dernière pièce (2 mm dans les taraudages du NEMA 11, limités à 2,5 mm),
    et les écrous sont en prise sur toute leur hauteur. Ce contrôle a fait allonger les 4 vis du
    palier et du support d'azimut (M3×10 → M3×12, avec une rondelle sur les lumières) : elles ne
    mordaient que de 2 mm.
  * Ce contrôle a conduit à revoir plusieurs fixations : la roue d'azimut est vissée par en
    dessous de la vis qui la parcourt, et les vis du fond n'ont plus leur tête sur la colonne.
    Le palier et le support d'azimut sont vissés par-dessus, et des lamages laissent la place
    aux têtes des vis des moteurs.
* **Engrènement** : les vis sont calées sur leurs roues, avec les dents en prise et sans
  chevauchement :
  * à −2°, 40° et 92° d'élévation ;
  * à des azimuts quelconques (37° et 113°), ce qui valide la loi de rotation de la vis
    d'azimut.

  Sur la vis d'azimut, il reste un recouvrement de 0,2 mm³. Il vient de la roue modélisée
  à dents droites, alors qu'une vraie roue de vis sans fin est taillée à la fraise-mère.
* **Garde sur toute la plage de mouvement** (élévation de −2° à +92°, azimut sur 360°,
  `python scripts/generate_tracker.py --balayage`, environ 11 min) :
  * partie qui bascule (panneau + chapeau) face à tout le reste : 2,0 mm, entre les flancs
    du chapeau et les bras de la chape ; en butée basse, le cadre du panneau passe à
    10,6 mm du socle. Seuls les bossages des flancs viennent plus près : à 0,1 mm des
    bagues intérieures des roulements de pivots, ce qui est voulu (voir « Roulements ») ;
  * denture roue / vis d'élévation : contact flanc contre flanc, sans aucun chevauchement
    de −2° à 92° (vérifié tous les 15°) ;
  * chape, moteurs et vis face à la partie fixe (socle, trépied, faisceau) : 1,0 mm au plus
    près, entre l'accouplement d'azimut et le voile de la roue fixe.
* **Stabilité** : basculement sans ancrage à 25,2° dans la pire orientation du panneau
  (`scripts/optimisation_angle.py`).
* **Relecture** des fichiers STEP produits : 201 solides, géométrie valide.

## 10. Limites

* Il s'agit d'une maquette de conception, pas d'un matériel qualifié pour le vol.
* Le panneau de 356 × 253 mm est un panneau terrestre (verre, EVA, boîte de jonction en
  plastique). Sur la Lune, les cycles thermiques et le vide le dégraderaient.
* Les moteurs NEMA du commerce ne sont pas prévus pour le vide ni pour −173 °C. Il faut
  leur équivalent en version vide ou spatiale : même taille, même couple, même pilotage.
  De même, les photodiodes BPW34 du capteur solaire sont des composants du commerce
  (§ 3 et § 17).
* Les roues des vis sont modélisées à dents droites. Les vraies roues sont taillées pour
  leur vis (dents inclinées et creusées), ce qui augmente la portée et la durée de vie.
* Sur Terre, le trépied non ancré bascule vers 16 m/s de vent : l'ancrer pour les
  essais en extérieur.
* Le dimensionnement mécanique (efforts, lancement, thermique) reste à faire une fois la
  masse définitive connue. Trois points sont déjà identifiés pour une version de vol :
  * **verrou de lancement** : au lancement (≈ 15 g), le panneau non équilibré ferait
    environ 13,5 N·m sur l'axe d'élévation, à la limite des dents de bronze. Il faut le
    brider à plat pendant le voyage, puis le libérer une fois posé ;
  * **logements de roulements en titane**, ou avec des bagues en acier : entre −173 °C et
    +127 °C, un logement en aluminium serrerait le 6806 de 0,11 mm de plus à froid et lui
    laisserait 0,06 mm de jeu à chaud ;
  * **capots sur les engrenages**, avec des passages en chicane : la poussière de régolithe
    est très abrasive. Les roulements, eux, sont déjà protégés par leurs flasques.

---

# Partie B — La démonstration sur Terre (tête imprimée en PETG)

La même tête, imprimée en PETG, avec le panneau et le capteur solaire, vissée sur un
trépied photo grand public (§ 18) :

| Vue d'ensemble, panneau à 40° | Côté moteurs |
|---|---|
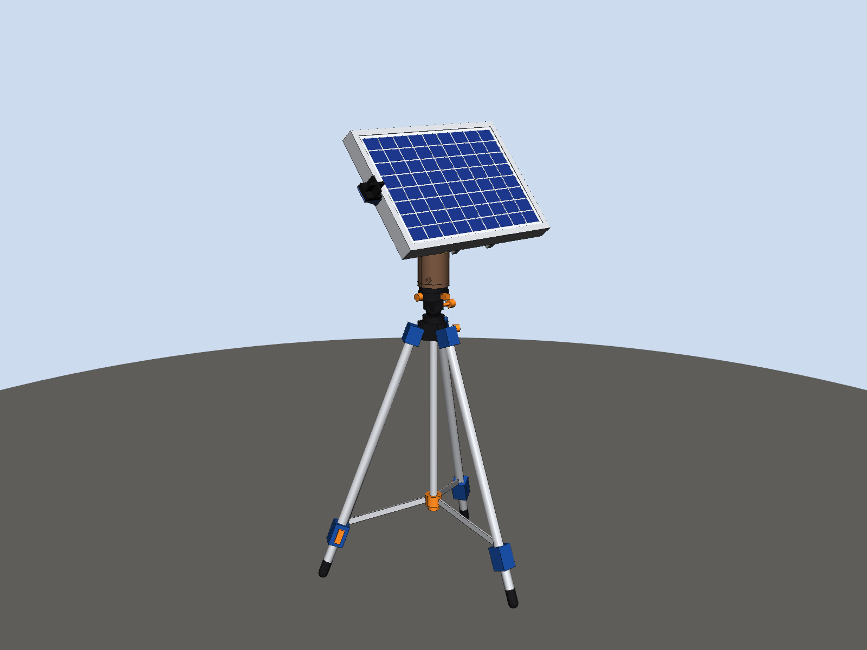
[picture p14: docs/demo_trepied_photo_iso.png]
Sur un trépied photo
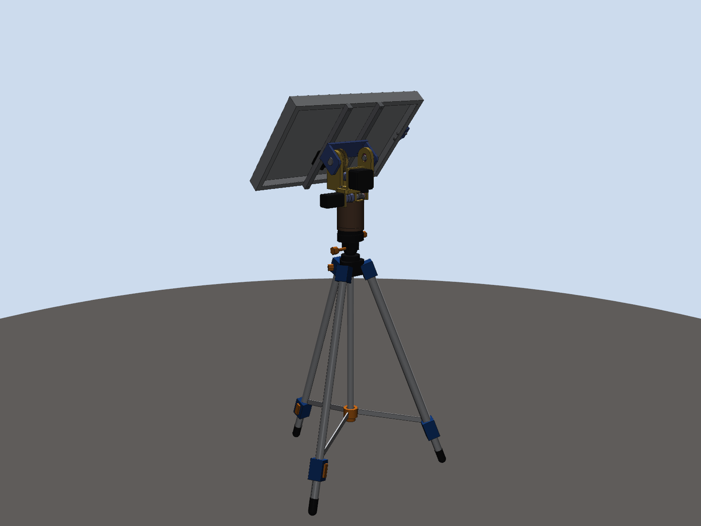
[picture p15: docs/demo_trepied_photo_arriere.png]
|  |  |
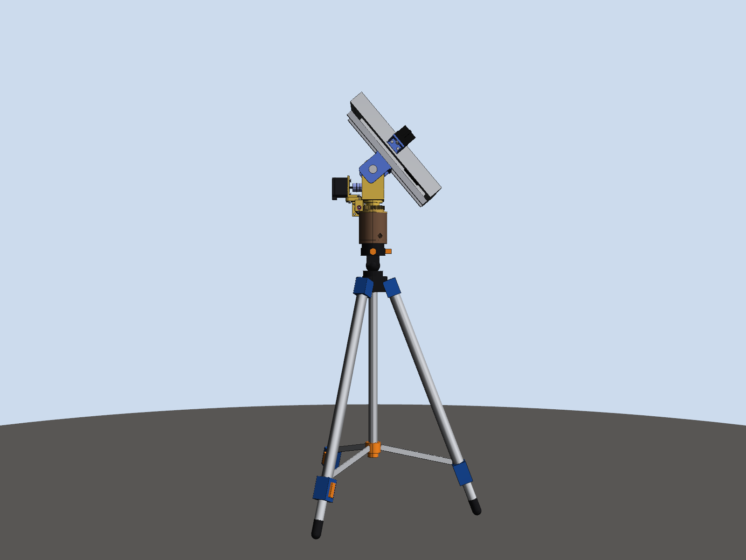
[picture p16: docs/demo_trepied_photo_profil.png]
De profil
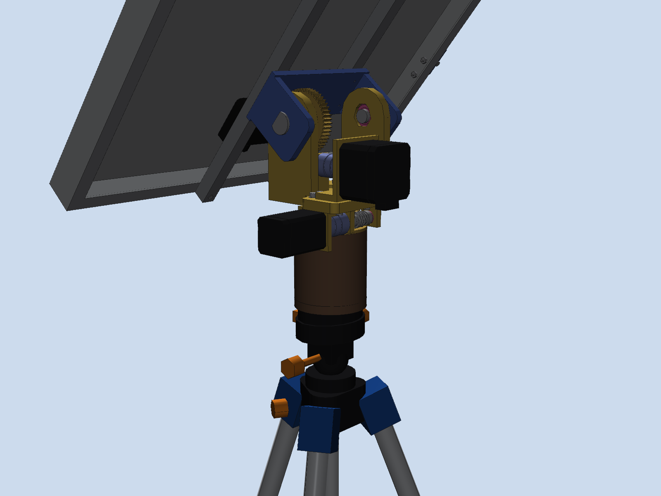
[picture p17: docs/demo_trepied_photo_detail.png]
La tête sur la rotule du trépied
|  |  |

## 11. Du cas réel à la démonstration : ce qui change

Pour la démonstration, toute la partie rotative est imprimée en PETG, **vis sans fin
comprises**. Restent en métal : le trépied, les deux rails du panneau, et les pièces du
commerce qu'on ne peut pas imprimer de façon fiable (roulements, arbres Ø5 des vis sans fin,
moteurs, vis). Les **pivots d'élévation sont imprimés** eux aussi.

Les fichiers sont dans **`CAO/Demo_Terre_PETG/`**. Ce sont les mêmes pièces que le cas réel,
générées avec le jeu de cotes `"petg"` : les trous et les dentures ont des jeux qui
compensent l'impression, et quelques formes sont adaptées pour s'imprimer sans support.
L'assemblage imprimé complet, avec roulements, arbres, moteurs et toutes les vis, a été vérifié
par le script :
* **aucune interférence** entre pièces, vis comprises ;
* chaque tête de vis a sa place, et aucune vis ne dépasse de son trou ;
* les vis et les roues **engrènent sans chevauchement** à −2°, 30° et 92° d'élévation et à
  plusieurs azimuts ;
* garde de 2 mm de la partie basculante sur toute la course.

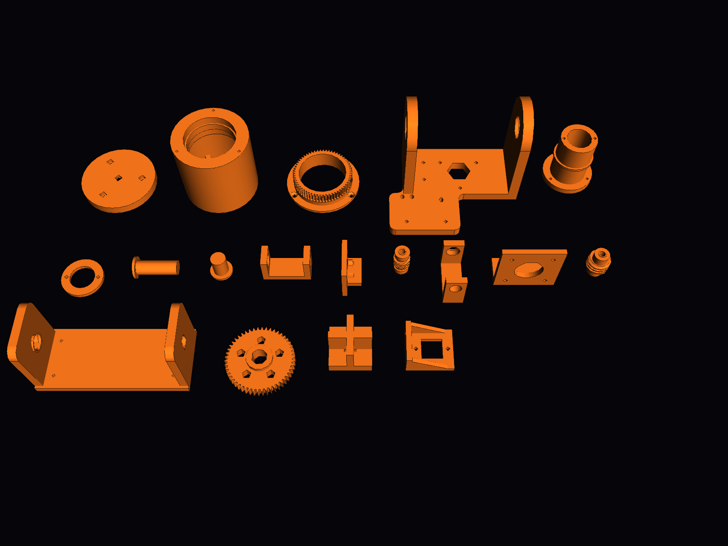
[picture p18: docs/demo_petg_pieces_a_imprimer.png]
Pièces à imprimer


**Ce qui ne change pas** : l'architecture de la tête (§ 1), les rapports 50:1 et 60:1, les
moteurs, le panneau et sa fixation (§ 2), le capteur solaire et son principe (§ 3), et
l'électronique.

**Ce qui change, pièce par pièce :**

| Élément | Cas réel (Lune) | Démonstration sur Terre |
|---|---|---|
| Socle, fond, chape, chapeau en U, paliers et supports de moteurs | Al 6061-T6 anodisé | **PETG imprimé** (le moyeu de la chape est imprimé à part) |
| Rondelle d'arrêt du moyeu | Inox 17-4PH | **PETG imprimé** |
| Roues des vis sans fin (azimut et élévation) | Bronze CuSn12 | **PETG imprimé** |
| Vis sans fin | Inox 17-4PH | **PETG imprimé** |
| Arbres des vis sans fin Ø5 | Inox 17-4PH | Acier, non imprimés : tige Ø5 rectifiée |
| Pivots d'élévation | Inox 17-4PH, Ø8 (dont un en D), sur 608 | **PETG imprimé**, Ø12 (l'entraîné en D), sur 6801 |
| Accouplements | Al 7075-T73 | Accouplements flexibles alu 5/5 du commerce |
| Roulements | 6806, 608, 685 **ZZ** en acier 440C, lubrification sèche (MoS₂) | 6806, **6801**, 685 **ZZ** (ou 2RS) en acier standard, graissés à vie d'origine |
| Lubrification des vis et des roues | MoS₂ sec | Graisse PTFE |
| Visserie | Inox ou titane | Vis CHC acier M3 et M2,5 |
| Moteurs | Version vide / spatiale (même taille) | NEMA 17 et NEMA 11 du commerce |
| Rails du panneau | Al 6061-T6 | Aluminium, non imprimés |
| Ferrures et colliers du trépied, axes, vis d'ancrage | Ti-6Al-4V | Non imprimés (métal) |
| Tubes de jambes, colonne, entretoises, patins | Al 7075-T73 anodisé dur | Non imprimés (aluminium) |
| Cadre du panneau | Al 6063-T5 | Al 6063-T5 (panneau du commerce) |
| Capteur solaire : boîtier à croix et équerre | Al 6061-T6 anodisé noir, fenêtre en silice fondue, photodiodes qualifiées pour le spatial | **PETG imprimé** (boîtier en PETG noir), photodiodes BPW34 du commerce |

**Les chiffres, côte à côte :**

| Grandeur | Cas réel | Démonstration PETG |
|---|---|---|
| Support | Trépied du projet (colonne Ø50), axe d'élévation à 700 mm du sol | Trépied photo (vis 1/4"), axe à 758 mm sur le trépied modélisé (§ 18) |
| Pivots d'élévation | Inox Ø8 sur roulements 608 | PETG Ø12 sur roulements 6801 |
| Masse de la tête (hors panneau) | 1,86 kg | 1,20 kg |
| Partie qui bascule (panneau, chapeau, roue, rails, capteur) | 1,73 kg, centre de gravité à 55,7 mm de l'axe | 1,50 kg, centre de gravité à 62,0 mm de l'axe |
| Courant du moteur d'élévation | 1,0 A | 0,6 A, pour ménager les dents en PETG |
| Marge d'élévation, vent de 10 m/s | ×2,7 | ×1,6 |
| Marge d'azimut, vent de 10 m/s | ×2,3 | ×2,3 |
| Lubrification des vis et des roues | MoS₂ sec | Graisse PTFE (obligatoire) |
| Roulements | Acier 440C, ZZ, MoS₂ | Acier standard, ZZ (ou 2RS), graissés d'origine |

## 12. Pièces à imprimer (`a_imprimer/`, déjà orientées sur le plateau)

| Pièce | Qté | Orientation (déjà appliquée) | Remarque |
|---|---|---|---|
| `Socle` | 1 | Debout, ouverture en bas | Cône à 45° sous le logement du 6806 bas : pas de support |
| `Fond_Socle` | 1 | Dessus sur le plateau | Se visse sur la vis 1/4" d'un trépied photo : écrou 1/4" pris dans un logement hexagonal |
| `Roue_Azimut_Fixe` | 1 | Dessous plat sur le plateau | Denture m0,8 : buse 0,25 mm conseillée (voir réglages) |
| `Chape` | 1 | Plaque sur le plateau, bras vers le haut | Plus grande pièce : 108 × 84 × 88 mm |
| `Moyeu_Chape` | 1 | Collerette sur le plateau | Imprimé à part pour que la chape tienne à plat ; vissé sous la chape (3 × M3) |
| `Bague_Arret_Moyeu` | 1 | À plat | |
| `Chapeau_U` | 1 | Plaque sur le plateau, flancs vers le haut | Alésage Ø12 en D côté roue ; un bossage Ø14,2 sur la face intérieure de chaque flanc |
| `Roue_Elevation` | 1 | À plat, moyeu en haut | Alésage Ø12 en D |
| `Pivot_Entraine` | 1 | Couché sur son méplat | Ø12 en D, 34 mm tête comprise ; porte la roue. 100 % de remplissage |
| `Pivot_Libre` | 1 | Debout, tête en bas | Ø12, 19 mm tête comprise. 100 % de remplissage |
| `Vis_Elevation`, `Vis_Azimut` | 1 + 1 | Debout, axe vertical | 100 % de remplissage ; bordure (brim) conseillée |
| `Palier_Vis_Elevation`, `Palier_Vis_Azimut` | 1 + 1 | Semelle sur le plateau | Lèvre de 1 mm côté extérieur de chaque joue : le 685 s'enfonce depuis l'intérieur du U |
| `Support_Moteur_Elevation`, `Support_Moteur_Azimut` | 1 + 1 | Semelle sur le plateau | |
| `Capteur_Solaire_Boitier` | 1 | Croix en haut | **PETG noir**, 100 % de remplissage : il doit être opaque (§ 17) |
| `Capteur_Solaire_Support` | 1 | Plaque sur le plateau, âme vers le haut | Équerre du capteur solaire, vissée sur le petit côté du cadre |

Environ 305 g de PETG pour la tête (406 g si tout était plein), plus 26 g pour le capteur
solaire.

**Réglages conseillés** :
* PETG, couches de 0,2 mm ;
* 4 périmètres, 40 % de remplissage gyroïde ;
* **100 %** pour les deux vis, les deux roues et les deux pivots ;
* compensation de la patte d'éléphant (≈ 0,2 mm) ;
* aucun support ;
* teinte claire de préférence : un PETG noir en plein soleil d'été peut approcher sa
  température de ramollissement (≈ 80 °C).

**Pour les quatre pièces dentées** : filet des vis de 0,95 mm (élévation) et 0,76 mm
(azimut) en tête, denture m0,8 de la roue d'azimut. Ça s'imprime avec une buse de 0,4 mm,
mais une **buse de 0,25 mm et des couches de 0,1 mm** donnent des dents nettement plus
justes.

## 13. Pièces à acheter

La liste complète, avec les noms à chercher sur les sites marchands, les quantités, les prix
indicatifs et l'électronique (ESP32, drivers, alimentation), est dans
**[`LISTE_ACHATS.md`](LISTE_ACHATS.md)**. En résumé, pour la mécanique :

| Article | Qté |
|---|---|
| Roulement **6806ZZ** (ISO 61806-2Z ; ou 6806-2RS), 30 × 42 × 7 mm | 2 |
| Roulement **6801ZZ** (ISO 61801-2Z ; ou 6801-2RS), 12 × 21 × 5 mm | 2 |
| Roulement **685ZZ** (ou 685-2RS), 5 × 11 × 5 mm — **pas le 685 ouvert, large de 3 mm** | 4 |
| Tige acier rectifiée Ø5, coupée à 52,5 mm (arbres des vis) : **le seul axe acier** | 2 |
| Accouplement flexible alu 5 mm / 5 mm, Ø19 × 25 mm (à chercher : `flexible shaft coupling 5mm x 5mm D19 L25`) | 2 |
| NEMA 17 34 mm (Usongshine 17HS3401, 0,34 N·m) et NEMA 11 45 mm (11HS18-0674S) | 1 + 1 |
| Vis CHC M3 : 6 × M3×8, 7 × M3×10, 11 × M3×12, 8 × M3×14 | 32 |
| Rondelle M3 (ISO 7089, 3,2 × 7 × 0,5), sous les vis d'azimut posées sur les lumières | 4 |
| Écrou 1/4"-20 UNC (filetage photo, 7/16" sur plats) | 1 |
| Écrou M3 (panneau sur les rails, équerre du capteur solaire) | 6 |
| Vis à tête fraisée M3×8 (roue d'azimut) | 3 |
| Vis CHC M2,5×6 (NEMA 11 : ses taraudages ne font que 2,5 mm) | 4 |
| Vis sans tête M3×4 (blocage des vis sans fin sur leur arbre) | 2 |
| Graisse PTFE (vis, roues) | 1 |
| Photodiodes BPW34, résistances de 1 kΩ et de 10 kΩ, condensateurs de 100 nF (capteur solaire) | 4 + 4 + 4 + 4 |

Les deux pivots d'élévation sont **imprimés** (`Pivot_Entraine`, `Pivot_Libre`) : il n'y a
plus d'axe Ø8 à acheter. Ils passent à **Ø12** et les 608 deviennent des **6801** (12 × 21 × 5),
car un pivot PETG de Ø8 ne tiendrait pas le couple de la roue d'élévation (voir § 19).
Leur tête Ø18 de 2 mm sert d'épaulement contre le flanc du chapeau.

### Roulements de la démonstration

Ce sont ceux du cas réel (§ 1), en acier standard, sauf à l'élévation : les pivots imprimés
Ø12 tournent dans des **6801** au lieu des 608.

| Réf. | Dimensions (Ø int. × Ø ext. × largeur) | Qté | Emplacement |
|---|---|---|---|
| **6801** (ISO 61801) | 12 × 21 × 5 mm | 2 | Élévation : dans les bras de la chape, sur les pivots imprimés Ø12. Appui sur la bague intérieure : bossage Ø14,2 du chapeau, à 0,25 mm. Appui sur la bague extérieure : alésage Ø19,5 du bras |

* Prendre de préférence des **ZZ**. Ils sont graissés à vie d'origine : ne pas les ouvrir ni
  les regraisser.
  * Les joints des 2RS frottent sur la bague intérieure. Les deux 6806-2RS freinent
    l'azimut d'environ 0,15 N·m (estimation), soit le tiers du couple du vent de 10 m/s.
  * Avec des 2RS, la marge de l'azimut au vent passe de ×2,3 à ×1,6 (vis graissée), et
    au-dessous de ×1 si la vis tourne à sec.
  * L'élévation n'est presque pas touchée : ×1,6 → ×1,5.
* **685** : prendre une version **protégée, ZZ ou 2RS**. Le 685 ouvert ne fait que 3 mm de
  large, alors que les paliers sont prévus pour 5 mm.
* **Montage** : enfoncer un roulement en poussant sur la bague qu'on emmanche. Dans un
  logement, c'est la bague extérieure : utiliser une douille de son diamètre, jamais un
  outil posé sur la flasque.

### Moteurs

Modèle retenu pour l'élévation : **Usongshine 17HS3401, 0,34 N·m à 1,0 A**, avec un
connecteur JST PH à 6 broches. Son plan est vérifié : taraudages M3 profonds de 4,5 mm au
moins, centrage Ø22 × 2, trous à 31 mm, axe Ø5 × 23,5. Un autre 17HS3401 convient s'il est
annoncé à **0,28 N·m au moins**. Certains vendeurs vendent sous la même référence une version
à 0,23 N·m, trop juste. En version PETG, régler le courant pour obtenir environ 0,20 N·m de
maintien (0,6 A pour ce moteur, § 19).

Pour l'azimut : **NEMA 11 de 45 mm, 11HS18-0674S** (0,10 N·m, 0,67 A). Ses taraudages ne
font qu'environ 2,5 mm de profondeur : vis M2,5×6, pas plus longues.

## 14. Jeux d'ajustement et éprouvette

| Ajustement | Cas réel | PETG | Pourquoi |
|---|---|---|---|
| Logements de roulements (608 / 6801, 685, 6806) | nominal | **+0,15 mm** | Les trous imprimés sortent plus petits ; on obtient un serrage léger du roulement |
| Alésage d'un axe (Ø5 acier des vis ; pivot Ø8 acier ou Ø12 PETG dans le chapeau et la roue) | nominal | **+0,10 mm**, en D côté roue (méplat à 5,25 mm de l'axe pour le Ø12) | Serré. Le méplat transmet le couple de la roue au chapeau, et une vis de pression bloque chaque vis sans fin |
| Pivots imprimés dans les 6801 | Ø8 acier | **Ø11,95** | Les diamètres extérieurs imprimés sortent un peu plus gros : serrage léger de la bague intérieure |
| Moyeu de la chape dans les 6806 | Ø30 | **Ø29,95** | Serrage léger de la bague intérieure |
| Fixation sur le trépied | Téton Ø45,5 dans la colonne Ø46 | **Écrou 1/4" captif**, logement de 11,4 mm sur plats (écrou de 11,1) | La vis du trépied tire l'écrou sur un plancher de 1,6 mm et serre le fond sur le plateau |
| Trous de passage M3 / M2,5 | 3,4 / 2,9 | **3,5 / 3,0** | |
| Avant-trous M3 | 2,5 (taraudés) | **2,8** | Vis auto-taraudées dans le PETG, 3,5 mm de prise au moins (vérifié par le script) |
| Centrage Ø22 des moteurs | 22,5 | **22,4** | |
| Jeu de denture des roues | 0,10 / 0,12 mm | **0,30 mm** | Imprécision des dents imprimées |
| Filet des vis | aminci de 0,15 m | **non aminci, tête raccourcie (0,85 m)** | Tout le jeu est pris sur la roue, et le filet reste assez épais pour l'impression |
| Entraxe vis / roue | nominal | **+0,15 mm**, puis réglé au montage | Lumières en azimut, cales en élévation |
| Bossages du chapeau sur les bagues intérieures des roulements de pivots | 0,10 mm par côté | **0,25 mm** par côté | Règlent le jeu axial du chapeau (0,5 mm en tout en PETG). Si le chapeau serre, poncer un bossage |
| Épaulements des moyeux des vis sur les 685 | 0,15 mm par côté | 0,15 mm par côté | Calage axial de la vis entre ses roulements |
| **Trous d'axe horizontal à l'impression** : logements des 6801 (bras de la chape) et des 685 (joues des paliers), alésages des pivots dans le chapeau, centrages des moteurs | cylindriques | **en goutte** | Le haut d'un trou horizontal imprimé s'affaisse : il sortirait ovale et trop petit. La goutte ajoute deux pans à 45° vers le haut, tronqués 0,6 mm au-dessus du cercle. Elle s'imprime sans support, et le roulement ou l'axe porte sur le reste du cercle. Les trous verticaux (6806, roues, vis) restent ronds |

**Imprimer d'abord l'éprouvette** `Eprouvette_Ajustements.stl`, avec les mêmes réglages
que les pièces :

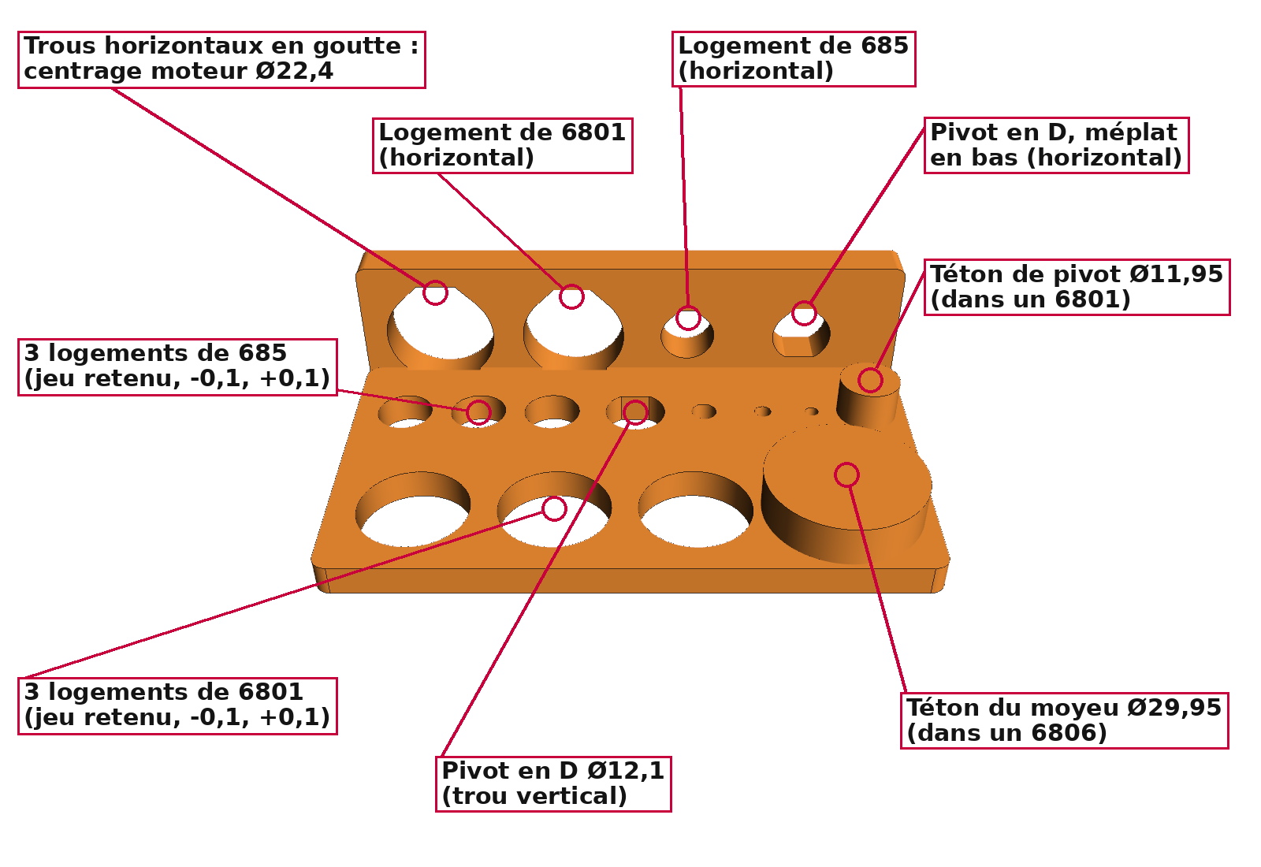
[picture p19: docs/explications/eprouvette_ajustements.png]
Éprouvette de réglage


* trois logements de 6801 et trois de 685 : le jeu retenu, −0,1 mm et +0,1 mm ;
* un alésage Ø12 en D, un Ø5, un passage et un avant-trou M3 ;
* un téton Ø29,95 pour le 6806 et un téton Ø11,95 pour le 6801 (essayer un vrai roulement
  dessus : il doit entrer en forçant légèrement) ;
* sur la paroi debout, les **trous horizontaux en goutte**, imprimés comme sur les pièces :
  centrage moteur Ø22,4, logement de 6801, logement de 685, alésage de pivot en D (méplat
  en bas).

Ce qu'on doit obtenir :
* les roulements entrent **en forçant légèrement**, à la main ou avec un serre-joint, et ne
  ressortent pas tout seuls ;
* le centrage du moteur se pose sans forcer ;
* le pivot entre dans son alésage en D sans jeu, en poussant fort.

Un roulement qui tombe tout seul : le jeu est trop grand. Un roulement qui ne rentre pas même
au serre-joint : le jeu est trop petit.

Si ton imprimante préfère un autre logement :
1. change la valeur dans `AJUSTEMENTS["petg"]`, en tête de `scripts/generate_tracker.py` ;
2. relance `python scripts/generate_tete_vis_sans_fin.py`.

Toutes les pièces sont alors régénérées avec ce jeu.

**Retouches possibles au montage**, car une imprimante n'est jamais exacte au dixième près :
* la vis sans fin serre entre ses deux 685 : poncer légèrement l'épaulement Ø6,5 d'un moyeu ;
* le chapeau serre entre les bras de la chape : poncer un bossage ;
* un pivot entre trop dur dans le chapeau : passer un foret Ø12 à la main, sans perceuse ;
* engrènements : réglés au montage (lumières en azimut, cales en élévation), voir l'étape 9.

## 15. Ordre de montage

| Le palier d'une vis sans fin | La vis sans fin imprimée |
|---|---|
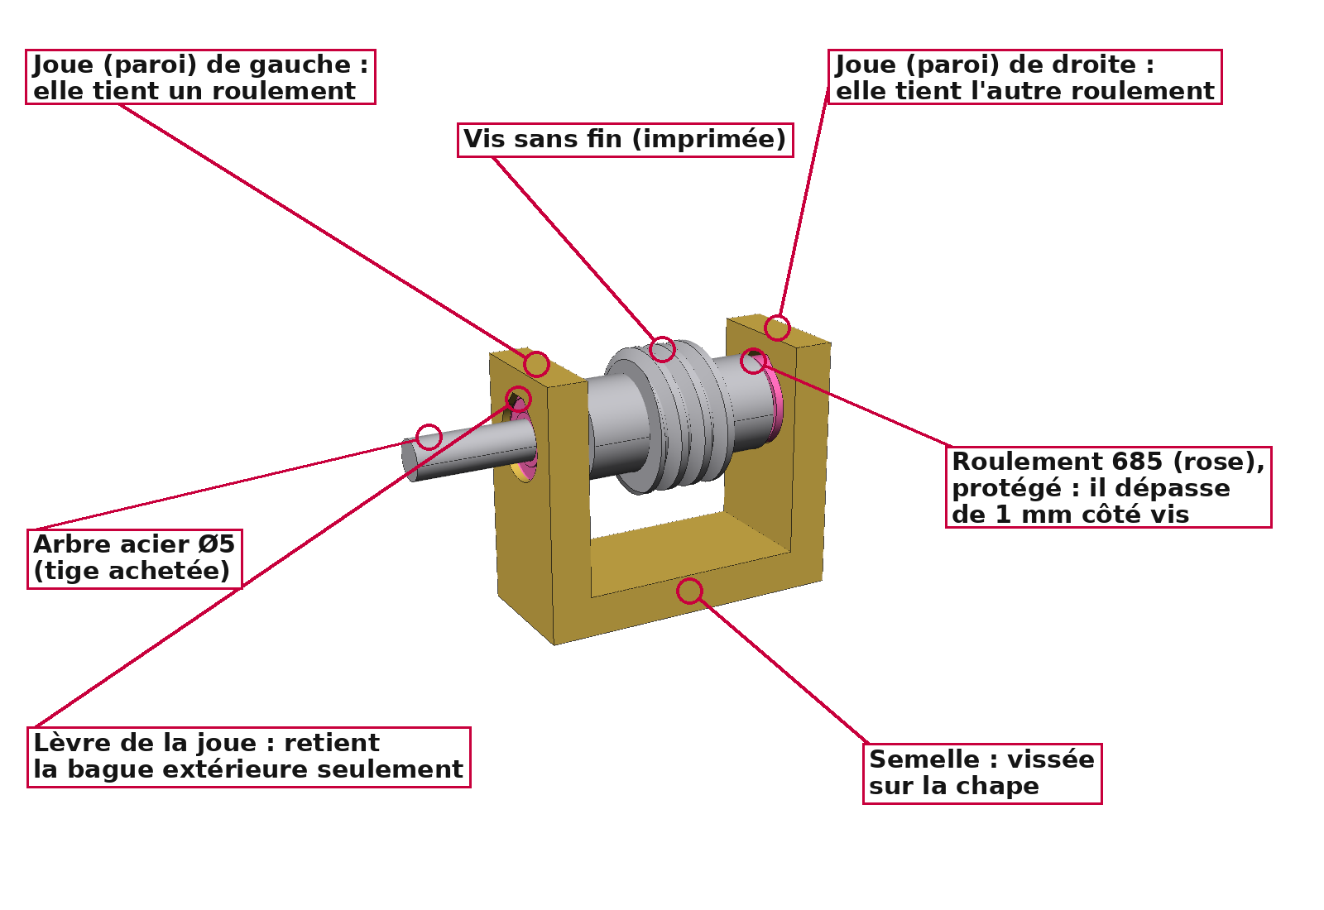
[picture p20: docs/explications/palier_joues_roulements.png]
Palier : joues, roulements, arbre
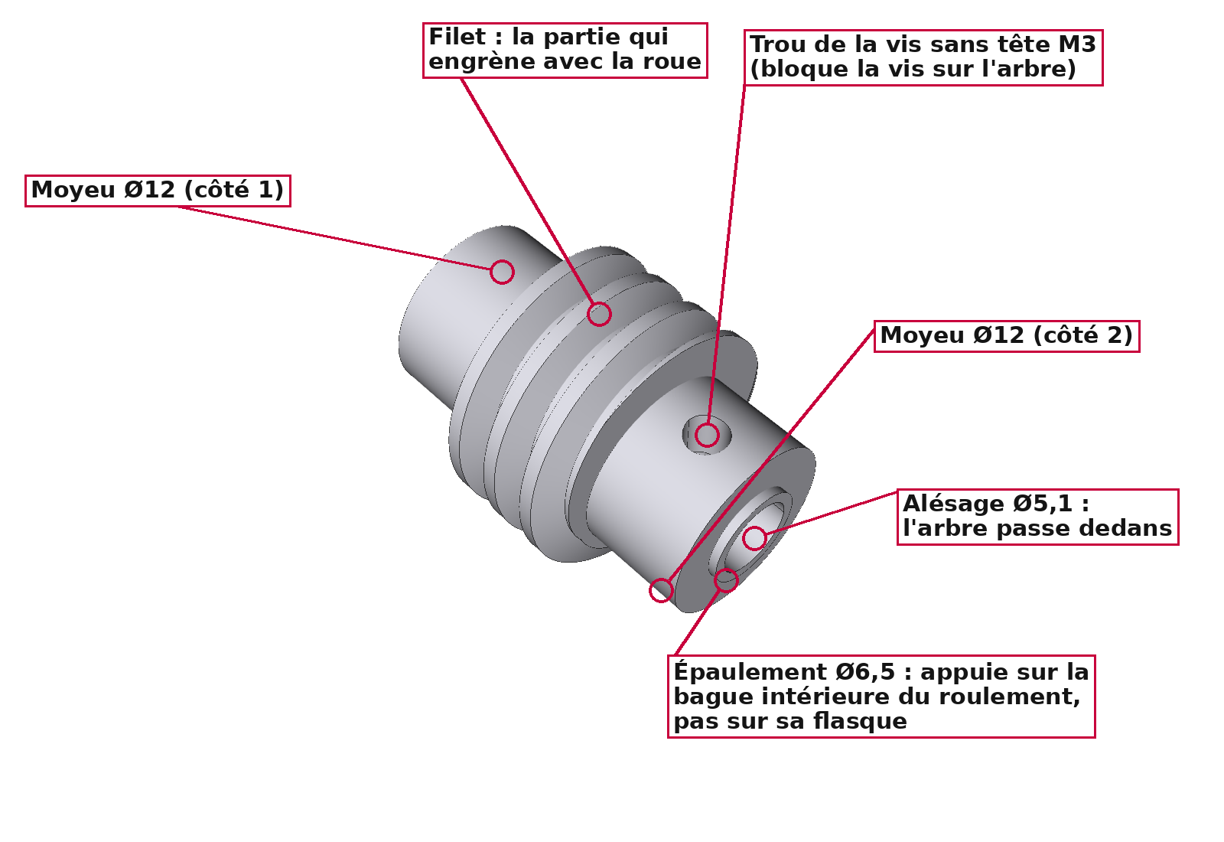
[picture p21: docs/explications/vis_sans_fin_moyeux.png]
Vis sans fin : filet, moyeux
|  |  |

| L'axe d'élévation imprimé : pivots PETG Ø12, roulements 6801, roue |
|---|
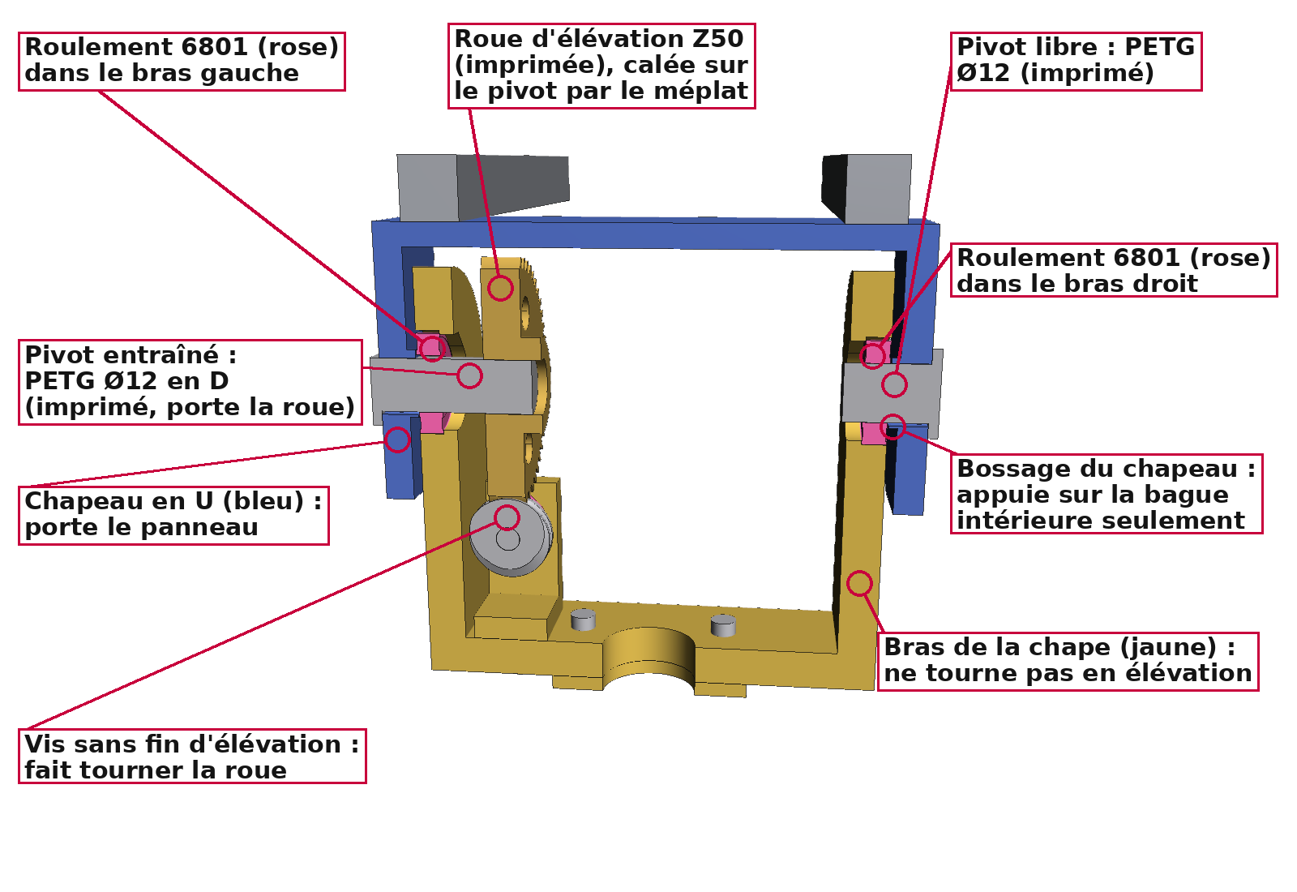
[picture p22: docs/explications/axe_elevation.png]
Axe d'élévation
|  |

* **Le palier** est la pièce en U qui porte une vis sans fin. Ses deux parois sont les
  **joues** : chacune tient un roulement 685, et l'arbre acier Ø5 les traverse. Côté
  extérieur, une **lèvre** de 1 mm retient la bague extérieure du roulement : le 685
  s'enfonce depuis l'intérieur du U jusqu'à cette lèvre, et dépasse de 1 mm côté vis.
* **La vis sans fin imprimée** a, de chaque côté du filet, un **moyeu Ø12**. Les moyeux
  viennent en appui sur les bagues intérieures des 685 par un épaulement Ø6,5, qui ne
  touche pas la flasque. Ils calent la vis entre les joues.
  Une vis sans tête M3×4 dans un moyeu bloque la vis sans fin sur l'arbre.
* **L'accouplement flexible** relie l'axe du moteur à l'arbre :
  * 12,5 mm de chaque axe entrent dans l'accouplement, avec environ 1 mm d'écart entre les
    deux bouts ;
  * sa vis de serrage se serre sur le méplat de l'axe du moteur.

1. **Socle** : presser le 6806 bas par-dessous, jusqu'à l'épaulement, puis le 6806 haut
   par-dessus. Pousser sur la bague extérieure (douille ou tube de Ø40 à 42), jamais sur la
   flasque.
2. **Roue d'azimut** : la poser à plat sur le socle et la fixer par 3 vis fraisées M3×8, qui
   doivent affleurer : la vis d'azimut passe juste au-dessus.
3. **Moyeu** : l'enfiler par le haut, à travers la roue et les deux roulements. Visser la
   rondelle d'arrêt par-dessous (2 × M3×8).
4. **Fond** : poser l'écrou 1/4" dans son logement hexagonal, par le dessus. Visser ensuite
   le fond sous le socle avec 3 × M3×10, têtes noyées par-dessous : l'écrou est alors
   prisonnier. Poser la tête sur le trépied photo et la visser sur la vis 1/4" du plateau.
5. **Chape** : sur l'établi, presser les deux 6801 dans les bras, par l'extérieur, jusqu'à
   l'épaulement. Monter ensuite la
   chaîne d'élévation :
   * le palier avec ses deux 685 (enfoncés depuis l'intérieur du U jusqu'à la lèvre), la vis
     sur sa tige Ø5 et sa vis de pression ;
   * l'accouplement, le support et le NEMA 17.

   Ces pièces sont vissées par-dessous la chape.
6. **Chapeau** : le présenter sur la chape, mettre la roue d'élévation entre les bras, puis
   enfiler le pivot imprimé en D à travers le flanc, le 6801 et la roue, méplat aligné avec
   ceux du flanc et de la roue. Mettre le pivot libre de l'autre côté, à travers le flanc
   et le 6801. Les deux pivots sont serrés dans le chapeau : une goutte de colle
   cyanoacrylate sous la tête les empêche de ressortir. Les bossages des flancs viennent
   contre les bagues intérieures des 6801 : le chapeau doit tourner librement, avec un
   léger jeu axial.
7. **Chape sur le moyeu** : 3 × M3×12 par-dessus.
8. **Chaîne d'azimut** : glisser le palier d'azimut (685, vis, tige) sous la chape, la vis
   venant en prise radialement avec la roue fixe. Mettre ensuite le support, le NEMA 11 et
   l'accouplement. Ces 4 vis M3×12 se mettent par-dessus la chape, dans les lumières, chacune
   avec une rondelle M3 sous la tête.
9. **Réglage des engrènements** (vis et roues graissées) :
   * en azimut, rapprocher le palier dans ses lumières jusqu'à supprimer le jeu, sans
     point dur sur un tour complet ;
   * en élévation, caler le palier par des rondelles ou du clinquant de 0,1 à 0,3 mm
     s'il y a trop de jeu.
10. **Rails et panneau** : les rails se vissent par-dessus le chapeau (4 × M3×14, têtes
    noyées dans les rails). Poser ensuite le panneau sur les rails. Dans chaque bout de rail,
    passer une vis M3×14 par-dessous à travers le rail et l'aile arrière du cadre, puis
    serrer un écrou M3 posé dans le cadre. On l'atteint par le dos ouvert du panneau.
11. **Capteur solaire** (§ 17) : coller les 4 BPW34 dans le boîtier et les câbler, visser le
    boîtier sur son équerre (2 × M3×10 par-dessous), puis l'équerre contre le petit côté du
    cadre, côté du pivot libre (2 × M3×10, écrous M3 posés dans le cadre).

## 16. Commande par ESP32

* **Drivers : 2 × TMC2209**, logique en 3,3 V. Ils sont pilotés par UART, sur un bus commun,
  avec les adresses 0 et 1 fixées par MS1/MS2.
* **Câblage** :
  * élévation : STEP GPIO 25, DIR GPIO 26 ;
  * azimut : STEP GPIO 32, DIR GPIO 33 ;
  * EN commun : GPIO 27 ;
  * UART : TX GPIO 17 vers PDN_UART à travers 1 kΩ, RX GPIO 16 ;
  * fins de course : GPIO 18 et 19, avec pull-up interne.
* **Alimentation : 12 V**, par exemple une batterie LiFePO4 4S de 12,8 V, avec 100 µF au
  plus près de chaque driver. L'ESP32 est alimenté par un abaisseur 12 V → 5 V.
* **Réglages** :
  * courant de marche (`rms_current`) : 1,0 A pour le NEMA 17 (**0,6 A en version PETG**,
    pour ne pas casser les dents si l'élévation bute), 0,67 A pour le NEMA 11 ;
  * 16 micro-pas, StealthChop ;
  * à l'arrêt : drivers désactivés par EN. Ne jamais laisser les moteurs alimentés en
    permanence : le NEMA 11 dissipe alors environ 6 W et le NEMA 17 environ 2 W, assez
    pour ramollir leurs supports en PETG.
* **Branchement du NEMA 17 (Usongshine 17HS3401)** : connecteur JST PH à 6 broches. Une
  bobine relie les broches 1 et 4, l'autre les broches 3 et 6 (vérifier au multimètre : faible
  résistance entre les deux fils d'une même bobine, circuit ouvert entre les deux bobines).
* **Branchement du NEMA 11 (11HS18-0674S)** : bobine A = noir (A+) et vert (A−), bobine B =
  rouge (B+) et bleu (B−), vers les bornes A et B du TMC2209. Au multimètre, on doit lire
  environ 6,8 Ω entre les deux fils d'une même bobine. Si le moteur tourne à l'envers,
  inverser le sens dans le programme.
* **Bibliothèques Arduino** : `FastAccelStepper`, qui génère les impulsions STEP en matériel
  sur l'ESP32, avec rampes d'accélération, et `TMCStepper`, pour le courant et le micro-pas
  par UART.
* **Capteur solaire** : 4 photodiodes BPW34 sur 4 entrées analogiques de l'ADC1 (GPIO 36,
  39, 34 et 35), avec une résistance de 1 kΩ chacune. Branchement au § 17, programme au § 3.
* **Origine** :
  * un micro-switch en butée basse d'élévation (−2°) ;
  * un capteur à effet Hall et un aimant sur la roue fixe pour l'azimut.

  La détection de calage sans capteur (StallGuard) n'est pas fiable à basse vitesse,
  surtout derrière une vis sans fin.
* Pour la démonstration, l'ESP32, les drivers et l'alimentation se posent au pied du trépied.
  Les câbles descendent de la tête par le passe-câble du socle.

## 17. Capteur solaire de la démonstration

Le capteur est celui du § 3 : même boîtier, même croix, mêmes photodiodes BPW34. Pour la
démonstration, le boîtier et son équerre sont imprimés.

| Pièce | Impression |
|---|---|
| `Capteur_Solaire_Boitier` | **PETG noir**, croix en haut, **100 %** de remplissage (18 g). Un PETG clair laisse passer la lumière à travers les murs et fausse la mesure. À défaut, le peindre en noir mat, intérieur des logements compris. Il chauffe au soleil comme tout objet noir, mais ne porte aucune charge |
| `Capteur_Solaire_Support` | N'importe quelle couleur, plaque sur le plateau (8 g). Les trous de l'âme sont en goutte |

1. Repérer la cathode de chaque BPW34 au multimètre, en position diode. Quand l'appareil
   affiche environ 0,5 V, la pointe rouge est sur l'anode et la noire sur la cathode.
2. Glisser chaque BPW34 dans son logement **par en dessous**, face transparente vers le
   haut, jusqu'au plancher. La pousser contre le coin du logement **du côté de la croix**, de
   la même façon pour les quatre, puis la bloquer par un point de colle chaude par-dessous.
3. Relier les 4 cathodes au fil du 3,3 V, et souder un fil sur chaque anode. Isoler les
   soudures (gaine thermorétractable ou colle chaude).
4. Faire passer le câble (5 fils : 3,3 V et les 4 signaux) par le passage carré de
   l'équerre, puis le long d'un rail et avec les câbles des moteurs. Laisser une boucle près
   de l'axe d'élévation.

**Branchement**, identique pour chacune des 4 photodiodes. Les résistances sont à côté de
l'ESP32, pas dans le capteur :

```
3,3 V ──────── cathode   BPW34   anode ──┬───────┬──────► entrée analogique (ADC1)
                                         │       │
                                       1 kΩ    100 nF
                                         │       │
GND ─────────────────────────────────────┴───────┘
```

**La résistance : 1 kΩ, à couche métallique, ±1 %, 1/4 W.**
* En plein soleil (≈ 1000 W/m²), la fenêtre de 2,2 × 2,2 mm reçoit environ 4,8 mW. La BPW34
  en tire environ 0,3 A/W sur le spectre solaire, soit **≈ 1,5 mA**, entre 1,2 et 2 mA selon
  le ciel et l'exemplaire.
* Avec 1 kΩ, cela fait **≈ 1,5 V** sur l'entrée, entre 1,2 et 2 V. C'est sous la limite de
  lecture précise de l'ADC (≈ 2,4 V avec l'atténuation 11 dB), avec une bonne résolution :
  ≈ 1900 points sur 4096, et une erreur de 0,1° change le signal d'environ 30 points.
* La photodiode garde au moins 1,3 V de polarisation inverse (3,3 V − 2 V) : sa réponse reste
  linéaire. La résistance ne dissipe que ≈ 2 mW.
* ±1 % et couche métallique : les 4 résistances restent égales et varient peu avec la
  température, ce qui compte puisque le programme compare les 4 signaux. L'étalonnage au
  papier calque (§ 3) corrige ce qui reste.
* **En intérieur, sous une lampe**, la lumière est 10 à 50 fois plus faible que le soleil :
  avec 1 kΩ, le signal ne ferait que quelques dizaines de mV. Mettre alors **10 kΩ** à la
  place (0,3 à 1,5 V selon la lampe et sa distance).
* Si le signal dépasse 2,4 V en plein soleil (rare), mettre deux 1 kΩ en parallèle (500 Ω).
  S'il reste sous 0,3 V sous la lampe, mettre deux 10 kΩ en série (20 kΩ), ou rapprocher la
  lampe.
* Le **condensateur de 100 nF** (céramique, 50 V) en parallèle sur chaque résistance filtre le
  bruit : avec 1 kΩ, il lisse au-delà d'environ 1,6 kHz, bien plus vite que le Soleil ne bouge.
* Utiliser des entrées de l'**ADC1**, car l'ADC2 ne marche pas quand le Wi-Fi est actif :
  * ESP32 DevKitC (WROOM-32) : **GPIO 36, 39, 34 et 35**. Ce sont des entrées seules, libres
    avec le câblage du § 16 ;
  * Heltec WiFi LoRa 32 V4 (ESP32-S3) : l'ADC1 correspond aux GPIO 1 à 10. Prendre 4 broches
    de ce groupe que la carte n'utilise pas déjà (radio LoRa, mesure de la batterie, GPS) :
    les vérifier sur le brochage de la carte.
* Lecture : atténuation 11 dB (`analogSetAttenuation(ADC_11db)`), moyenne de 32 à 64
  lectures pour lisser le bruit.

### Stratégie de suivi sur Terre : le calcul et les photodiodes ensemble

1. **Le calcul fait le gros du pointage.** Avec l'heure et la position données par le GPS du
   Heltec V4 (ou réglées à la main), l'ESP32 calcule l'azimut et la hauteur du Soleil. Le
   calcul marche le matin, sous les nuages, et permet de revenir vers l'est la nuit. Mais il
   ne connaît pas l'orientation de la tête : où est le nord, et si le trépied est de niveau.
2. **Les photodiodes corrigent l'erreur restante** dès que le Soleil est assez fort. L'ESP32
   **retient l'écart** entre les angles calculés et les angles où le capteur a centré le
   Soleil. Quand un nuage passe, le calcul seul reste juste.

## 18. Sur un trépied photo grand public

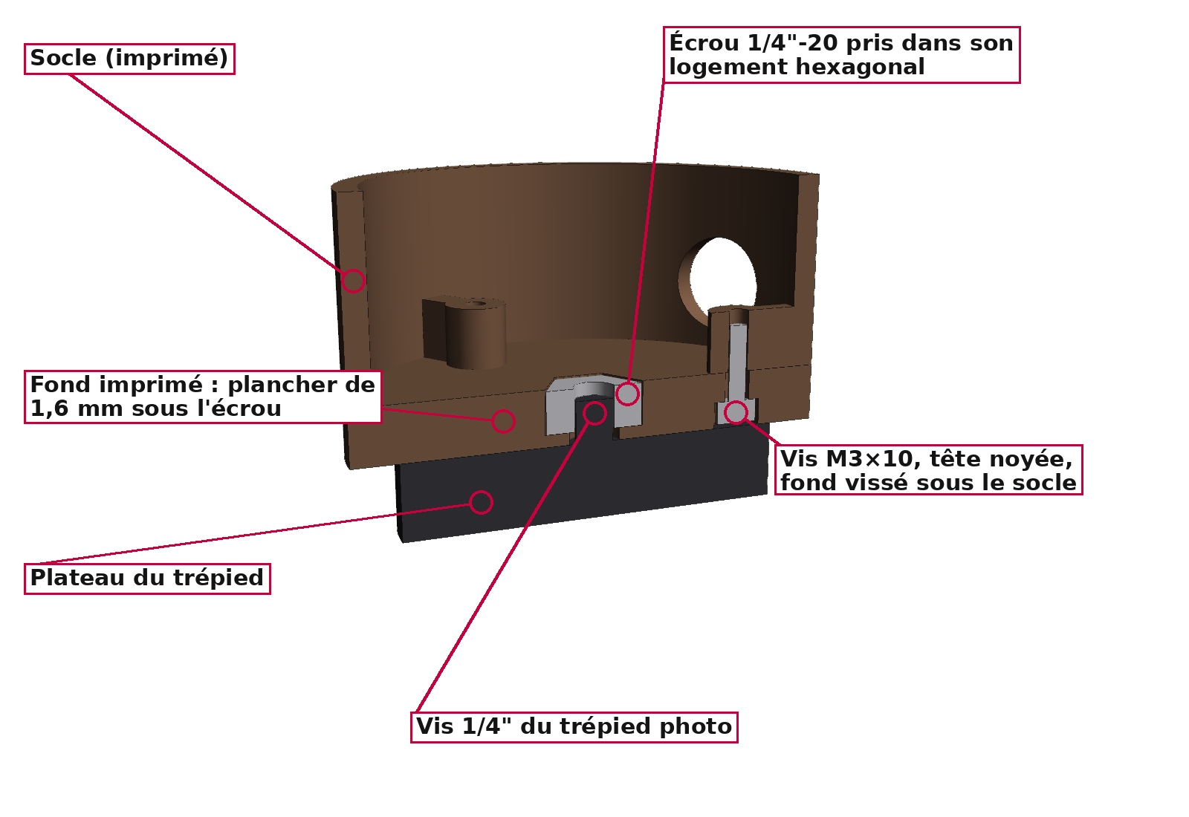
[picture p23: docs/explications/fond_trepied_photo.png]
Fond sur trépied photo


La version PETG se visse directement sur la **vis 1/4" du plateau d'un trépied photo**.
Le fond contient un écrou 1/4"-20 pris dans un logement hexagonal. Les câbles sortent
par le passe-câble du socle, puisque le centre est occupé par la vis. Le cas réel garde sa
colonne Ø50.

* **Serrer fermement** la tête sur la vis. C'est ce serrage qui empêche la tête de tourner
  sur le trépied quand le moteur d'azimut force : il lui faut environ 0,5 N·m dans le vent,
  et au plus 1,7 N·m s'il bute. Un serrage à la main, ferme, sur le caoutchouc du plateau,
  en tient plusieurs N·m.
* La vis du trépied doit dépasser du plateau d'au moins **4,5 mm**. Au-delà de 7 mm, elle
  dépasse simplement dans le socle, sans gêner.
* **Bloquer la rotule** du trépied (panoramique et inclinaison) et la mettre **de niveau**.
  La tête et le panneau pèsent 2,4 kg : vérifier la charge maximale du trépied.
* **Stabilité** : un trépied photo léger bascule bien plus tôt que le trépied du projet.
  Le calcul est fait ci-dessous pour un trépied photo courant.

### Le trépied modélisé : dimensions et stabilité

Les images de la démonstration montée sur ce trépied sont en tête de la Partie B.

L'assemblage complet est dans **`CAO/Demo_Terre_PETG/Demo_Trepied.step`** : tête
PETG, panneau, capteur solaire et trépied, posé sur le sol en y = 0. Il est généré par
`scripts/generate_demo_trepied.py`.

Le trépied y est modélisé simplement, à partir de deux cotes mesurées :
* le dessus du plateau est à **600 mm** du sol (sans la vis 1/4" qui dépasse) ;
* les pointes des pieds sont à **230 mm** de l'axe, au sol.

Le reste (tubes, corps, rotule) est estimé sur les photos.

**Ce que ça donne :**
* l'axe d'élévation est à **758 mm** du sol. Panneau vertical, son bord haut est à environ
  0,89 m, et son point le plus bas à environ 0,63 m ;
* **aucune interférence**. Le panneau passe à 33 mm au plus près du plateau du trépied (panneau
  vertical) : les molettes de la rotule restent en dessous ;
* charge sur la rotule : tête et panneau font **2,4 kg**. Leur centre de gravité s'écarte
  jusqu'à 29 mm de l'axe, ce qui fait 0,7 N·m que les blocages de la rotule doivent tenir ;
* masse du trépied estimée à 0,9 kg (à peser : plus lourd, il serait un peu plus stable).

**Stabilité.** C'est le point faible : les pieds ne sont qu'à 23 cm de l'axe. Les bords du
triangle d'appui sont donc à 11,5 cm du centre, alors que l'axe est à 76 cm du sol et que le
panneau déporte son centre de gravité. Calcul fait dans toutes les orientations du panneau, avec
un vent perpendiculaire au panneau (Cx 1,2, vent sur le trépied négligé) :

| Lest suspendu sous le trépied | Pire orientation : pente de basculement | Pire orientation : vent de basculement | Panneau tourné vers une jambe |
|---|---|---|---|
| Aucun | 8,6° | **7,9 m/s (28 km/h)** | 9,2° ; 9,4 m/s (34 km/h) |
| 2 kg | 14,0° | 10,4 m/s (37 km/h) | 14,6° ; 11,6 m/s (42 km/h) |
| 3 kg | 16,5° | **11,4 m/s (41 km/h)** | 17,1° ; 12,6 m/s (45 km/h) |

* **En intérieur, sans lest** : ça tient, sur un sol à peu près plat.
* **Dehors, un lest de 2 à 3 kg est indispensable** : un sac de sable ou une bouteille d'eau,
  suspendu sous la colonne, juste au-dessus du sol. Sans lest, une brise de 28 km/h suffit à
  le renverser.
* **Orienter une jambe vers le sud**, vers le Soleil de midi. Le panneau regarde alors vers
  cette jambe la plus grande partie de la journée, et un vent de dos le pousse vers elle :
  c'est l'orientation la plus favorable (colonne de droite).
* Au-dessus d'environ 10 m/s de vent, ou en partant, mettre le panneau à plat (élévation 90°).
* **Rotule** : serrer fermement les deux blocages (panoramique et inclinaison), mettre le
  plateau de niveau avec la bulle, et vérifier que le clip du plateau est bien verrouillé. Si
  la rotule se dévisse du trépied et que le filetage dessous est un 1/4", la tête PETG peut s'y
  visser directement : plus rigide, et 7 cm plus bas.

## 19. Couples, marges et tenue de la version PETG

Calculés par `scripts/generate_tete_vis_sans_fin.py`, avec la partie qui bascule de la
démonstration : 1,50 kg, centre de gravité à 62,0 mm de l'axe. Vis et roues graissées,
roulements ZZ :

| Marge = disponible / besoin | Terre, intérieur | Terre, extérieur (vent 10 m/s) |
|---|---|---|
| Élévation, moteur limité à 0,6 A (2,08 N·m disponibles) | ×2,3 | **×1,6** |
| Azimut (1,22 N·m disponibles) | ×41 | **×2,3** |

| Ce qu'on regarde | Version PETG | Verdict |
|---|---|---|
| Part du couple moteur utilisée, élévation | 61 % dehors (vent 10 m/s), 44 % dedans, à 0,6 A | Bien dimensionné dehors |
| Part du couple moteur utilisée, azimut | 43 % dehors, 2 % dedans | Dimensionné par le vent |
| Dents en PETG, élévation | 16 MPa en marche dehors, 37 MPa moteur calé | C'est la vraie limite : d'où le courant limité à 0,6 A |
| Dents en PETG, azimut | 7 MPa en marche dehors, 22 MPa moteur calé | Large |
| Pivot entraîné Ø12 en PETG | 4 MPa en marche, 9 MPa moteur calé | ×3 au calage, ×8 en marche |

* **Le cas qui dimensionne est la démonstration dehors, avec 10 m/s de vent.** Les marges y
  sont de ×1,6 (élévation, à 0,6 A) à ×2,3 (azimut). Pour un moteur pas à pas, on vise ×1,5
  à ×2 : l'élévation de la version PETG est donc au bas de la plage, pas au-dessus.
* **Énergie** : alimentés, les moteurs consomment environ 2 W (NEMA 17 à 0,6 A) et 6 W
  (NEMA 11). Les drivers sont coupés entre deux corrections : quelques dizaines de mW en
  moyenne au lieu de 8 W.

### Ce que change le PETG en fonctionnement

* **Couples** : les vis et roues en PETG doivent être **graissées**.
  * Graissées (μ ≈ 0,15) : ×1,6 en élévation (moteur limité à 0,6 A, voir plus bas) et
    ×2,3 en azimut avec un vent de 10 m/s ; ×2,3 et ×40 en intérieur.
  * À sec (μ ≈ 0,30), l'élévation ne suit plus dans le vent (×1,0) et n'a plus que ×1,3 en
    intérieur : **graisser**.
  * Ces marges sont celles des roulements **ZZ**. Avec des 2RS, les joints freinent : en
    azimut, ×1,6 graissé et moins de ×1 à sec (voir § 13).
* **Tenue moteurs coupés** : encore plus sûre qu'avec acier et bronze, car le frottement du
  PETG est plus élevé. Les deux vis sont irréversibles, même avec des vibrations.
* **Dents en PETG** : limiter le courant du moteur d'élévation à **0,6 A** (au lieu de
  1,0 A) avec le moteur Usongshine de 0,34 N·m.
  * Si l'élévation se bloque (butée, fin de course raté), le moteur calé donne alors au plus
    3,0 N·m à la roue. Cela fait environ 37 MPa en pied de dent, soit 74 % de la résistance
    du PETG.
  * La marge au vent de 10 m/s reste de ×1,6, et de ×2,3 en intérieur.
  * À 1,0 A, ce moteur pousserait jusqu'à 5 N·m sur la roue en cas de blocage : environ
    60 MPa, les dents casseraient.
  * Le NEMA 11 d'azimut peut rester à 0,67 A : en butée, sa roue voit au plus 22 MPa.
* **Pivots imprimés Ø12** : le pivot entraîné transmet le couple de la roue au chapeau.
  * En marche (poids du panneau et vent de 10 m/s, ≈ 1,3 N·m), il travaille à environ
    4 MPa en torsion. Moteur calé à 0,6 A (3,0 N·m), environ 9 MPa : le tiers de la
    résistance au cisaillement du PETG (≈ 30 MPa).
  * Un pivot PETG de Ø8 monterait à 28 MPa, à la limite de la rupture : d'où le Ø12 et
    les roulements 6801.
  * Il s'imprime **couché**, pour que les couches suivent l'axe. Imprimé debout, il
    casserait en torsion entre deux couches.
  * Le pivot libre ne porte que la moitié du poids de la partie basculante (≈ 7 N) : il
    peut s'imprimer debout.
* **Fluage** : sous une charge permanente, le PETG se déforme lentement. Entre deux
  démonstrations, garer le panneau **à plat (élévation 90°)**, où la pesanteur ne charge
  presque plus la denture.

---

# Partie C — Fichiers, scripts, régénération et licence

## 20. Fichiers du dépôt

| Fichier | Contenu |
|---|---|
| **`CAO/Cas_Reel/`** | **Cas réel** (Lune), cotes nominales : |
| `CAO/Cas_Reel/Tracker_Lunaire_PoleSud.step` | **Assemblage principal** : pose de fonctionnement au pôle Sud (site Artemis), Soleil à +1,5°, panneau quasi vertical |
| `CAO/Cas_Reel/Tracker_Lunaire_LatitudeMoyenne.step` | Même assemblage, pose « sites Apollo » : Soleil à 50°, panneau incliné à 40° |
| `CAO/Cas_Reel/Tete_Rotative_VisSansFin.step` | La tête rotative seule, avec le haut de la colonne et le panneau monté à 40° |
| `CAO/Cas_Reel/pieces/*.step` | Toutes les pièces seules (trépied, tête, panneau, unité au sol), chacune dans son repère de construction |
| **`CAO/Demo_Terre_PETG/`** | **Démonstration sur Terre**, tête imprimée en 3D en PETG, avec les jeux d'ajustement (Partie B) : |
| `CAO/Demo_Terre_PETG/a_imprimer/*.stl` (et `.step`) | Les 18 pièces à imprimer (16 pour la tête, 2 pour le capteur solaire), déjà orientées et posées sur le plateau |
| `CAO/Demo_Terre_PETG/Tete_Rotative_PETG.step` | L'assemblage de la tête imprimée (avec roulements, arbres Ø5, moteurs et vis), pour vérifier le montage |
| `CAO/Demo_Terre_PETG/Eprouvette_Ajustements.stl` | Éprouvette à imprimer en premier pour régler les ajustements sur ton imprimante |
| `CAO/Demo_Terre_PETG/Demo_Trepied.step` | La démonstration complète sur un trépied photo grand public : tête PETG, panneau, capteur solaire et trépied (§ 18) |
| `docs/bilan_masse.csv` | Bilan de masse pièce par pièce (séparateur `;`, s'ouvre dans Excel) |
| `docs/apercu_*.png`, `docs/tete_vis_sans_fin_*.png`, `docs/demo_trepied_photo_*.png` | Rendus du tracker (iso, face, profil, arrière, détails), de la tête seule (dont deux coupes) et de la démonstration sur trépied photo |
| **`LISTE_ACHATS.md`** | **Liste d'achats** de la démonstration sur Terre : roulements, accouplements, arbres Ø5 des vis sans fin, moteurs, électronique, visserie, consommables, avec les noms à chercher et les quantités |
| `docs/explications/*.png` | Images annotées pour le montage : palier d'une vis sans fin (joues, roulements, arbre), vis sans fin imprimée (filet, moyeux, vis de blocage) axe d'élévation imprimé (pivots, roulements 6801, roue), éprouvette de réglage des ajustements, fond sur trépied photo, capteur solaire (vue et coupe) |
| `docs/optimisation_angle_jambes.md` | Optimisation de l'angle φ des jambes : exigences, résultats angle par angle, sensibilité |
| `scripts/generate_tracker.py` | Script paramétrique qui génère toute la CAO, le bilan de masse et les contrôles |
| `scripts/generate_tete_vis_sans_fin.py` | Exporte la tête seule, cale les vis, calcule les couples et la tenue moteurs coupés |
| `scripts/generate_demo_trepied.py` | Monte la tête PETG sur un trépied photo grand public, vérifie les interférences et calcule la stabilité (basculement, vent) |
| `scripts/optimisation_angle.py` | Calcule l'angle φ optimal des jambes à partir des masses de la CAO |
| `scripts/render_apercu.py`, `scripts/render_tete_vis_sans_fin.py`, `scripts/render_explications.py` | Génèrent les rendus PNG et les images annotées |
| `requirements.txt` | Dépendances Python (CadQuery) |
| `LICENSE` | Licence du projet : CC BY-NC-SA 4.0 (§ 23) |

## 21. Ouvrir dans SolidWorks

Un fichier SolidWorks natif (`.SLDASM` / `.SLDPRT`) ne peut être écrit que par SolidWorks
lui-même. Le format STEP AP214 fourni s'ouvre directement comme un assemblage complet,
avec les noms des pièces, les sous-assemblages et les couleurs.

1. **Fichier › Ouvrir**, type *STEP AP203/214/242 (\*.step; \*.stp)*, puis choisir
   `CAO/Cas_Reel/Tracker_Lunaire_PoleSud.step`.
2. Si SolidWorks demande un modèle de document, prendre l'assemblage et la pièce **en mm**.
3. **Fichier › Enregistrer sous › Assemblage (\*.sldasm)**. Au premier enregistrement,
   SolidWorks crée les fichiers `.SLDPRT` de chaque pièce.
   Pour tout regrouper dans un dossier, utiliser **Fichier › Pack and Go**.

Repère : **Y vertical**, c'est-à-dire que le plan de dessus de SolidWorks correspond au sol.
* L'origine est au sol, sur l'axe d'azimut (**axe Y**).
* L'axe d'élévation est horizontal (**axe X** dans la pose de référence), à Y = 700 mm.
  Le sommet de la colonne, sur lequel repose la tête, est à Y = 544 mm.
* Les pièces arrivent fixes, sans contraintes. Pour animer le tracker :
  * libérer `SA_Tete_Orientable` et ajouter une contrainte coaxiale entre le moyeu de la `Chape` et les `Roulement_6806` ;
  * libérer `SA_Panneau` et ajouter une contrainte coaxiale entre les pivots (`Pivot_Entraine`, `Pivot_Libre`) et les `Roulement_608` (`Roulement_6801` dans la version PETG) ;
  * ajouter des contraintes d'engrenage entre `Vis_Azimut` et `Roue_Azimut_Fixe` (rapport 1:60), puis entre `Vis_Elevation` et `Roue_Elevation` (1:50).

Arborescence :

```
Tracker_Lunaire_PoleSud
├── SA_Trepied            colonne, colliers, 3 × Jambe_n, 3 × entretoises, 3 × patins, 3 × vis d'ancrage
├── SA_Tete_Fixe          fond et socle Ø62, 2 roulements 6806, roue d'azimut fixe (bronze)
├── SA_Tete_Orientable    chape en U (jaune), vis + moteur d'azimut, vis + moteur d'élévation,
│   │                     paliers, accouplements, roulements                                  ← tourne en azimut (Y)
│   └── SA_Panneau        chapeau en U renversé (bleu), pivots, roue d'élévation (bronze),
│                         2 rails, cadre, laminé, cellules, boîte de jonction                 ← tourne en élévation (X)
├── SA_Unite_Sol          unité de contrôle / batterie + radiateur
└── SA_Faisceau           faisceau de câbles
```

## 22. Régénérer ou modifier la CAO

Les scripts sont dans `scripts/` et se lancent depuis la racine du dépôt. Tous les
paramètres sont regroupés en tête de `scripts/generate_tracker.py` :
* dans le dictionnaire `P` : dimensions du panneau, hauteur d'axe, décalage du panneau,
  angle et exigences du trépied ;
* dans `POSES` : les deux poses exportées ;
* dans les constantes de la tête : `Z_T`, `VIS_EL`, `VIS_AZ`, `MOT_EL`, `MOT_AZ`, et `PHASES`
  (calage des vis, donné par `scripts/generate_tete_vis_sans_fin.py`) ;
* dans `AJUSTEMENTS` : les deux jeux de cotes de la tête, `"reel"` et `"petg"` (Partie B).

Les cas de charge (`VENT_EL`, `VENT_AZ`, `K_RUN`, `MU_REPOS`…) sont en tête de
`scripts/generate_tete_vis_sans_fin.py`. Ceux du trépied photo (`TREPIED_DEMO`, lests) sont en tête
de `scripts/generate_demo_trepied.py`.

```bash
pip install -r requirements.txt
python scripts/generate_tracker.py                    # STEP + bilan de masse + contrôle d'interférences
python scripts/generate_tracker.py --balayage         # + garde sur toute la plage az/él
python scripts/generate_tete_vis_sans_fin.py          # tête seule (réel + PETG), fichiers à imprimer, couples, contrôles
python scripts/generate_demo_trepied.py               # démonstration sur trépied photo : STEP, contrôles, stabilité
xvfb-run -a python scripts/generate_demo_trepied.py --rendus   # ses rendus
python scripts/optimisation_angle.py                  # angle φ optimal des jambes (à reporter dans P["leg_angle"])
xvfb-run -a python scripts/render_apercu.py           # rendus du tracker (xvfb-run seulement sans écran)
xvfb-run -a python scripts/render_tete_vis_sans_fin.py             # rendus de la tête seule
xvfb-run -a python scripts/render_tete_vis_sans_fin.py --plateau   # pièces à imprimer sur le plateau
xvfb-run -a python scripts/render_explications.py                  # images annotées (docs/explications/)
```

## 23. Licence

Tout le projet (fichiers CAO STEP et STL, images, documents et scripts) est sous licence
**Creative Commons Attribution - Pas d'utilisation commerciale - Partage dans les mêmes
conditions 4.0 International (CC BY-NC-SA 4.0)**. Le texte complet est dans
[`LICENSE`](LICENSE).

| Autorisé | Interdit |
|---|---|
| Consulter, télécharger, imprimer les pièces, construire le tracker pour soi, pour un projet scolaire ou un club | Vendre les fichiers, les pièces imprimées ou un tracker construit d'après le projet |
| Modifier et améliorer le projet, et partager ces modifications | Utiliser le projet dans un produit ou un service payant |
| Le présenter (exposé, démonstration, salon) | Republier une version modifiée sous une autre licence, ou sans citer l'auteur |

**Pour réutiliser le projet**, il faut citer l'auteur et la licence, par exemple :
« Tracker solaire lunaire deux axes, par Gabrixl-m, sous licence CC BY-NC-SA 4.0 », avec un
lien vers ce dépôt. Pour un usage commercial, il faut une autorisation écrite de l'auteur :
le contacter par GitHub.

Les marques et références de produits citées (moteurs, roulements, photodiodes, magasins)
appartiennent à leurs propriétaires. Les logiciels utilisés par les scripts, comme CadQuery
(licence Apache 2.0), ne sont pas inclus dans ce dépôt et gardent leur propre licence.

---

# Bibliographie

## Choix du mode de rotation : le schéma azimut-élévation (AE)

**[1]** P. Garner, N. Phillips, A. Cawthorne, A. da Silva Curiel, P. Davies, L. Boland
(Surrey Satellite Technology Ltd, SSTL), *« Follow that Ground Station! And double the data
throughput using polarization diversity »*, 23rd Annual AIAA/USU Conference on Small
Satellites, Logan (Utah), 2009, article SSC09-VI-8.

Je me suis appuyé sur cet article pour choisir le mode de rotation du tracker. Il décrit le
développement par SSTL d'un mécanisme de pointage d'antenne à deux axes (APM) pour le
satellite d'observation NigeriaSat-2. Ce n'est pas un tracker solaire, mais le problème est
le même : orienter un objet plat vers une cible qui se déplace dans le ciel, avec un
mécanisme léger, peu coûteux et sobre en énergie.

**Ce que montre l'article :**
* **Orientation mécanique plutôt qu'électronique.** SSTL écarte les antennes à balayage
  électronique (complexes, chères, gourmandes, débattement limité) au profit d'un mécanisme
  orientable : faible consommation, grand débattement, facile à agrandir. L'article note
  même qu'un seul axe du mécanisme pourrait servir d'entraînement de panneau solaire (SADM).
* **Trois architectures à deux axes comparées** : X-Y, azimut-élévation (AE) et plateau
  oscillant (« swashplate »).
  * Le schéma **X-Y est rejeté**, car son débattement est insuffisant.
  * Les deux autres sont construits en modèles d'ingénierie et testés en endurance.
  * La conception finale retenue est **azimut-élévation**, avec les modules d'entraînement
    (moteurs, roulements, engrenages) mis au point sur le plateau oscillant.
* **Le résultat, l'APM AE-90**, est qualifié en vibrations et en vide thermique, et a dépassé
  100 000 cycles. Il pointe à mieux que 1°, sur ±270° en azimut et ±114,7° en élévation. Il
  pèse 2,7 kg et consomme environ 3,4 W quand les deux axes bougent.
* **Autres choix de conception** :
  * composants du commerce (COTS) pour réduire le coût ;
  * passage des câbles par l'axe d'azimut grâce à une boucle de câble (jusqu'à 540°),
    plutôt que par un collecteur tournant ;
  * axes équilibrés pour éviter un verrou de lancement.

**Ce que j'en ai repris :**

| Choix de l'article [1] | Dans ce tracker |
|---|---|
| Schéma **azimut-élévation** plutôt que X-Y, pour le débattement | Azimut sur ±180° et élévation de −2° à +92° : tout le ciel est couvert. Au pôle Sud lunaire, le Soleil fait le tour de l'horizon en un jour lunaire : l'azimut le suit naturellement |
| Un axe par coordonnée de la cible | Les deux coordonnées du Soleil (azimut, hauteur), calculées par l'ESP32, donnent directement les angles des deux moteurs : commande simple. Les deux erreurs du capteur solaire (haut / bas, gauche / droite) corrigent chacune un moteur (§ 3) |
| Boucle de câble plutôt qu'un collecteur tournant | Câbles par le moyeu creux de la chape, boucle dans le socle, azimut limité à ±180° puis retour |
| Composants du commerce | Moteurs NEMA 17 et 11, roulements standard (6806, 6801, 685), accouplements, ESP32 |
| Même module d'entraînement sur les deux axes | Chaque axe : moteur, accouplement, vis sans fin sur 2 roulements 685 dans un palier, roue |
| Orientation mécanique pour la faible consommation | Moteurs coupés entre deux corrections |

**Ce qui diffère, et pourquoi :**
* **La vitesse.** L'APM suit le passage d'un satellite à plus de 20°/s. Le Soleil avance de
  15°/h sur Terre et de 0,5°/h sur la Lune. J'ai donc choisi des **vis sans fin
  irréversibles** (50:1 et 60:1) plutôt que des axes équilibrés : elles tiennent le panneau
  moteurs coupés, sans contrepoids (voir § 1).
* **Le verrou de lancement.** SSTL équilibre ses deux axes pour s'en passer. Ici, le
  panneau n'est pas équilibré : une version lunaire réelle aura besoin d'un verrou de
  lancement (voir § 10).
* **La limite connue du schéma AE : le zénith.** Quand la cible passe près de la verticale,
  l'azimut doit tourner très vite pour la suivre.
  * Au pôle Sud lunaire, le Soleil reste à quelques degrés de l'horizon : le cas ne se
    présente jamais.
  * À La Réunion (21° S, sous les tropiques), le Soleil passe presque au zénith vers midi en
    été. Mais près du zénith, un retard d'azimut ne compte presque pas : 30° de retard à 88°
    de hauteur ne font qu'environ 1° d'erreur de pointage, soit moins de 0,02 % de perte.

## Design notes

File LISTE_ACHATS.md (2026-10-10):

# Liste d'achats — démonstration sur Terre (tête imprimée en PETG)

Tout ce qu'il faut acheter pour **une tête rotative à vis sans fin** en version PETG et son
**capteur solaire** (4 photodiodes sous une croix d'ombre, README § 3 et § 17), en plus des
pièces imprimées de `CAO/Demo_Terre_PETG/a_imprimer/` (voir README, Partie B, § 12).
Les deux pivots d'élévation sont **imprimés** : le seul axe en acier à acheter est la tige Ø5
des arbres des vis sans fin.

* La colonne « À chercher » donne le nom à taper sur les sites marchands (AliExpress,
  Amazon, etc.), où ces pièces sont presque toujours vendues sous leur nom anglais.
* Les prix sont **indicatifs** (ordre de grandeur, par article).
* Les roulements sont en **rose** dans les fichiers 3D. Ils sont tous **protégés** : prendre
  de préférence la version **ZZ** (flasques métalliques), sinon 2RS (joints caoutchouc).

| Palier d'une vis sans fin | Axe d'élévation imprimé |
|---|---|
| Palier : joues, roulements, arbre, vis | Axe d'élévation : pivots PETG, roulements 6801 |

---

## 1. Mécanique

| Article | Caractéristiques | Qté | À chercher | Où il va | ≈ Prix |
|---|---|---|---|---|---|
| **Roulement 6806ZZ** (ISO 61806-2Z) | 30 × 42 × 7 mm | 2 | `6806ZZ bearing 30x42x7` (ou `61806ZZ`) | Azimut : dans le socle, autour du moyeu de la chape | 3 € |
| **Roulement 6801ZZ** (ISO 61801-2Z) | 12 × 21 × 5 mm | 2 | `6801ZZ bearing 12x21x5` (ou `61801ZZ`) | Élévation : dans les bras de la chape, sur les pivots imprimés Ø12 | 1–2 € |
| **Roulement 685ZZ** | 5 × 11 × **5** mm | 4 | `685ZZ bearing 5x11x5` | Deux par vis sans fin, dans les joues des paliers | 1 € |
| **Accouplement flexible 5 mm / 5 mm** | Alésages Ø5 des deux côtés, Ø19 × 25 mm, alu | 2 | `flexible shaft coupling 5mm x 5mm D19 L25` | Relie l'axe de chaque moteur à l'arbre de sa vis sans fin (la pièce bleue) | 2–4 € |
| **Tige acier rectifiée Ø5** | Ø5 mm, au moins 110 mm | 1 | `linear shaft 5mm 150mm` (ou `5mm chrome steel rod`) | À couper en **2 × 52,5 mm** : les arbres des deux vis sans fin | 3–5 € |
| *ou* **Rond plein acier Ø5** (en magasin) | Acier laminé à chaud, Ø5 mm, 1 m (par exemple STANDERS chez Leroy Merlin) | 1 | `rond plein acier 5 mm` | Moins précis : voir « Pièges à éviter » | 4–5 € |

**Pièges à éviter** :
* **Arbres des vis** : une tige **lisse et pleine, en acier, Ø5**. Pas de tige filetée : les
  roulements porteraient sur les sommets du filet. Pas de tube, ni d'aluminium. Avec un rond
  plein laminé à chaud plutôt qu'une tige rectifiée :
  * le mesurer au pied à coulisse et garder les deux morceaux les plus réguliers ;
  * enlever le vernis là où vont les roulements, la vis sans fin et l'accouplement ;
  * entre 4,90 et 4,98 mm, coller les bagues intérieures des roulements à la colle à
    roulements ;
  * au-dessus de 5,00 mm, le poncer en le faisant tourner dans une perceuse (grain 400 à
    600) ;
  * limer un petit méplat sous la vis sans tête.
* **ZZ plutôt que 2RS** : les deux versions ont les mêmes cotes et vont toutes les deux
  dans les pièces. Mais les joints caoutchouc des 2RS frottent :
  * les deux 6806-2RS freinent l'azimut d'environ 0,15 N·m ;
  * la marge du moteur d'azimut au vent de 10 m/s passe alors de ×2,3 à ×1,6.

  Si tu as déjà des 2RS, ça marche, à condition de bien graisser les vis sans fin.
* **685** : prendre une version protégée, **ZZ** (ou 2RS). Le 685 « ouvert » ne fait que
  3 mm de large, alors que les joues sont prévues pour 5 mm.
* **Accouplement** : bien **5 mm des deux côtés**. Les modèles 5 mm / 8 mm, très courants,
  sont faits pour les vis trapézoïdales d'imprimante 3D.
* **6801** : c'est un roulement fin (5 mm de large), à ne pas confondre avec le 6001
  (12 × 28 × 8), plus gros. Vérifier **12 × 21 × 5** dans l'annonce.
* **Pas d'axe Ø8** : les pivots d'élévation sont les pièces imprimées `Pivot_Entraine`
  et `Pivot_Libre`, en Ø12. Un pivot PETG de Ø8 casserait sous le couple de la roue.

## 2. Moteurs et électronique

| Article | Caractéristiques | Qté | À chercher | Rôle | ≈ Prix |
|---|---|---|---|---|---|
| **Moteur pas à pas NEMA 17, 34 mm** (Usongshine 17HS3401) | 42 × 42 × 34 mm, **0,34 N·m (34 N·cm)**, 1,0 A, axe Ø5 × 23,5 à méplat, connecteur JST PH 6 broches | 1 | `Usongshine 17HS3401 34N.cm` | Élévation. **À régler à 0,6 A** en version PETG | 10–15 € |
| **Moteur pas à pas NEMA 11, 45 mm** | 28 × 28 × 45 mm, 0,095–0,10 N·m, 0,67 A, axe Ø5 | 1 | `11HS18-0674S nema 11 stepper` | Azimut | 15–25 € |
| **Driver TMC2209** | Module UART, 3,3 V logique | 2 | `TMC2209 stepper driver UART` | Un par moteur | 4–6 € |
| **ESP32** | Carte de développement ESP32-WROOM-32 | 1 | `ESP32 DevKitC WROOM-32` | Commande des deux moteurs | 6–10 € |
| **Alimentation 12 V** | En intérieur : bloc secteur 12 V 3 A. En extérieur : batterie LiFePO4 4S 12,8 V | 1 | `12V 3A power supply` / `LiFePO4 12V battery` | Puissance des moteurs | 10 € / 40–80 € |
| **Abaisseur 12 V → 5 V** | Module à découpage, 1 A au moins | 1 | `LM2596 buck converter` (ou `MP1584`) | Alimente l'ESP32 | 2 € |
| **Condensateur 100 µF 25 V** | Électrolytique | 2 | `100uF 25V capacitor` | Un au plus près de chaque driver | 0,2 € |
| **Fin de course** | Micro-switch à levier | 1 | `KW12 micro limit switch` (ou `endstop switch`) | Origine de l'élévation, en butée basse | 1 € |
| **Capteur à effet Hall + aimant** | Capteur A3144 (ou module KY-003) + aimant néodyme 5 × 2 mm | 1 + 1 | `A3144 hall sensor`, `neodymium magnet 5x2mm` | Origine de l'azimut | 2 € |
| **Câbles** | Câbles moteurs 4 fils (souvent fournis avec les moteurs), fils Dupont, câble souple 4 fils d'environ 1,5 m | — | `stepper motor cable 4 pin`, `dupont wires` | Liaisons | 5 € |
| **Photodiode BPW34** (Vishay ou Osram) | Photodiode PIN au silicium, boîtier 5,4 × 4,3 × 3,2 mm, surface sensible 7,5 mm² | 4 + 1 de rechange | `BPW34` (Gotronic : réf. 03472) | Capteur solaire, une par coin de la croix | 1 € |
| **Résistance 1 kΩ**, couche métallique, ±1 %, 1/4 W, 50 ppm/°C | Valeur pour le soleil, dehors : environ 1,5 V en plein soleil | 4 + 2 de rechange | `1k ohm metal film resistor 1% 1/4W` | Une par photodiode, de l'anode à la masse, à côté de l'ESP32 | 0,1 € |
| **Résistance 10 kΩ**, couche métallique, ±1 %, 1/4 W | Valeur pour les essais en intérieur, sous une lampe (10 à 50 fois moins de lumière que le soleil) | 4 | `10k ohm metal film resistor 1% 1/4W` | À la place des 1 kΩ, en intérieur | 0,1 € |
| **Condensateur céramique 100 nF**, 50 V, X7R | Filtre le bruit (constante de temps 0,1 ms avec 1 kΩ) | 4 | `100nF ceramic capacitor 50V` | Un par photodiode, en parallèle sur sa résistance | 0,1 € |
| **Câble 6 à 8 fils** | Environ 1,5 m. Un bout de câble réseau (8 fils) convient | 1 | `câble réseau`, `6 core cable` | Du capteur à l'ESP32 : 3,3 V et les 4 signaux | 2 € |
| Gaine thermorétractable fine | Ø1,5 à 2,5 mm | quelques cm | `heat shrink tube 2mm` | Isole les soudures des pattes des photodiodes | 1 € |

Le câblage (broches de l'ESP32, réglage des TMC2209, bibliothèques) est décrit dans le
README, § 16, « Commande par ESP32 ». Le branchement du capteur solaire est au § 17.

## 3. Visserie

Toute la visserie est **métrique à pas standard** (M3 × 0,5 et M2,5 × 0,45), sauf l'écrou du
trépied photo (1/4"-20 UNC). Prendre de l'**inox A2-70** (il ne rouille pas dehors), sinon de
l'acier zingué classe 8.8.

La longueur d'une vis CHC se mesure sous la tête ; celle d'une vis fraisée, hors tout. Chaque
longueur a été vérifiée dans la CAO par `scripts/generate_tete_vis_sans_fin.py` : la vis traverse
les pièces et mord dans la dernière sur la longueur indiquée (« prise »), sans toucher le fond
de son avant-trou ni dépasser là où quelque chose tourne.

**Vis**

| Vis (norme) | Qté | Où | Traverse | Se visse dans | Prise | Clé |
|---|---|---|---|---|---|---|
| **CHC M3 × 8** (ISO 4762 / DIN 912) | 2 | Rondelle d'arrêt sous le moyeu, par-dessous | Rondelle d'arrêt (3 mm) | Moyeu de la chape (avant-trou Ø2,8) | 5 mm | 2,5 mm |
| **CHC M3 × 8** | 4 | NEMA 17 sur son support | Support (4 mm) | Taraudages du moteur (4,5 mm de profondeur) | 4 mm | 2,5 mm |
| **CHC M3 × 10** | 3 | Fond sous le socle, par-dessous, têtes noyées | Fond (3,9 mm sous le lamage) | Socle | 6 mm | 2,5 mm |
| **CHC M3 × 10** | 2 | Équerre du capteur solaire contre le petit côté du cadre | Équerre (4 mm) + paroi du cadre (1,5 mm) | Écrou M3 posé dans le cadre | Écrou complet, dépasse de 2 mm | 2,5 mm |
| **CHC M3 × 10** | 2 | Boîtier du capteur sur son équerre, par-dessous | Équerre (4 mm) | Boîtier du capteur | 6 mm | 2,5 mm |
| **CHC M3 × 12** | 3 | Chape sur le moyeu, par-dessus | Chape (8 mm) | Moyeu de la chape | 4 mm | 2,5 mm |
| **CHC M3 × 12** | 4 | Palier et support moteur d'élévation, par-dessous la chape | Chape (8 mm) | Palier / support | 4 mm | 2,5 mm |
| **CHC M3 × 12** + rondelle | 4 | Palier et support moteur d'azimut, par-dessus la chape, dans les **lumières** | Rondelle (0,5 mm) + chape (8 mm) | Palier / support | 3,5 mm | 2,5 mm |
| **CHC M3 × 14** | 4 | Rails sur le chapeau, par-dessus, têtes noyées dans les rails | Rail (9,5 mm sous le lamage) | Chapeau en U | 4,5 mm | 2,5 mm |
| **CHC M3 × 14** | 4 | Cadre du panneau sur les rails, par-dessous, têtes noyées | Bout du rail (9,5 mm) + aile du cadre (1,5 mm) | Écrou M3 posé dans le cadre | Écrou complet, dépasse de 0,6 mm | 2,5 mm |
| **Tête fraisée M3 × 8** (ISO 10642 / DIN 7991) | 3 | Roue d'azimut sur le socle : elles doivent affleurer | Roue (fraisure) | Socle | 5,5 mm | 2 mm |
| **CHC M2,5 × 6** (ISO 4762) | 4 | NEMA 11 sur son support. Pas plus longues : ses taraudages ne font que 2,5 mm | Support (4 mm) | Taraudages du moteur | 2 mm | 2 mm |
| **Sans tête M3 × 4, bout plat** (ISO 4026 / DIN 913) | 2 | Une par vis sans fin, dans le trou radial du moyeu, serrée sur le méplat de l'arbre Ø5 | — | Moyeu de la vis sans fin | — | 1,5 mm |

Les vis de serrage des accouplements flexibles sont fournies avec eux.

**Écrous et rondelles**

| Article (norme) | Dimensions | Qté | Où |
|---|---|---|---|
| **Écrou hexagonal M3** (ISO 4032 / DIN 934) | 5,5 mm sur plats, 2,4 mm d'épaisseur | 6 | Posés dans le cadre du panneau : sur l'aile arrière, un par vis des rails (4) ; contre le petit côté, pour l'équerre du capteur (2) |
| **Écrou hexagonal 1/4"-20 UNC** (filetage photo) | 7/16" = 11,1 mm sur plats, 7/32" = 5,6 mm d'épaisseur (un contre-écrou de 4 mm convient aussi) | 1 | Pris dans le fond : la tête se visse sur la vis 1/4" du trépied photo. Ce n'est pas un écrou M6 : le pas est différent |
| **Rondelle plate M3** (ISO 7089 / DIN 125-A) | 3,2 × 7 × 0,5 mm | 4 | Sous la tête des 4 vis d'azimut posées sur les lumières de la chape. Sans elle, la tête Ø5,5 ne porterait que sur 0,4 mm aux deux bouts d'une lumière de 4,7 mm et s'enfoncerait dans le PETG |
| Rondelle plate M3 (ISO 7089), en plus | 3,2 × 7 × 0,5 mm | 8 | **Seulement si les rails sont en barre de 12 × 12** au lieu de 12 × 13 : deux rondelles empilées (1 mm) sous chaque vis, entre le rail et le chapeau |

**Pas d'autre rondelle** : ailleurs, les têtes sont noyées dans des lamages (Ø6,2 et Ø6,5, trop
étroits pour une rondelle) ou portent sur un trou rond, et les écrous du cadre portent sur
l'aluminium. Pas de rondelle fendue (Grower) : elle marquerait le PETG.

**Serrage**

* **Dans le PETG** (avant-trous Ø2,8, sans taraudage) : la vis taille son filet la première fois.
  Visser doucement, en revenant d'un demi-tour à chaque tour pour dégager, et s'arrêter dès que
  la tête touche, plus 1/8 de tour. Environ 0,3 à 0,4 N·m : la clé Allen tenue par le petit
  bras, entre deux doigts. Trop serrer arrache le filet.
* **Dans un écrou ou dans un moteur** : M3 environ 0,8 N·m (petit bras de la clé, serré
  fermement à la main) ; M2,5 environ 0,4 N·m.
* **Frein-filet** (Loctite 243, moyen, facultatif) : une goutte sur les 2 vis sans tête, qui
  vibrent avec les vis sans fin. Jamais dans le PETG.

**Clés Allen** : 1,5 mm (vis sans tête), 2 mm (M2,5 et vis fraisées M3), 2,5 mm (vis CHC M3).

**Récapitulatif à acheter** : CHC M3 × 8 : 6 ; M3 × 10 : 7 ; M3 × 12 : 11 ; M3 × 14 : 8 ;
fraisées M3 × 8 : 3 ; CHC M2,5 × 6 : 4 ; sans tête M3 × 4 : 2 ; écrous M3 : 6 ; écrou
1/4"-20 UNC : 1 ; rondelles M3 : 4 (12 avec des rails en 12 × 12). Prendre quelques vis de
rechange de chaque taille.

Le plus simple est d'acheter des coffrets en inox A2 :
* **vis CHC M3** (`M3 socket head screw assortment A2`), avec au moins 11 vis de 12 mm ;
* **vis CHC M2,5** (`M2.5 socket head screw`) ;
* **vis fraisées M3 × 8** (`M3x8 countersunk screw ISO 10642`) ;
* **vis sans tête M3 × 4** (`M3x4 set screw flat point`) ;
* **écrous M3** (`M3 hex nut DIN 934`) et **rondelles M3** (`M3 washer DIN 125`) ;
* un **écrou 1/4"-20 UNC** (`1/4-20 UNC hex nut`).

Compter 10 à 15 € en tout.

## 4. Pièces métalliques non imprimées

| Article | Caractéristiques | Qté | À chercher | Remarque |
|---|---|---|---|---|
| **Rails du panneau** | Barre alu 12 × 12 mm, 2 × 253 mm | 2 | `aluminium square bar 12mm` | Le modèle prévoit 12 × 13 mm : avec une barre de 12 × 12, mettre deux rondelles M3 (ISO 7089, 0,5 mm) sous chaque vis, entre le rail et le chapeau (voir § 3). Percer 4 trous Ø3,4 par rail : 2 à 14 mm de part et d'autre du milieu (vis du chapeau, lamage Ø6 × 3,5 dessus) et 1 à 6 mm de chaque bout (vis du panneau, lamage Ø6 × 3,5 dessous) |
| **Cadre du panneau** (celui du panneau acheté) | — | — | — | Percer 4 trous Ø3,4 dans l'aile arrière des deux grands côtés, au droit des rails : à 44 mm de part et d'autre du milieu, et à 6 mm du bord extérieur. L'aile doit faire au moins 10 mm de large. Pour le capteur solaire, percer aussi 2 trous Ø3,4 dans un **petit côté** (celui du pivot libre, à l'opposé de la roue d'élévation) : à 9 mm de part et d'autre du milieu et à 12 mm du dos du cadre, sous le laminé |

## 5. Consommables

| Article | Qté | À chercher | ≈ Prix |
|---|---|---|---|
| **Filament PETG 1,75 mm** (teinte claire de préférence) | 1 bobine de 1 kg (environ 300 g utilisés) | `PETG filament 1.75mm 1kg` | 20 € |
| **PETG noir** pour le boîtier du capteur solaire, qui doit être opaque | Environ 20 g : un reste de bobine suffit. À défaut, imprimer en clair et peindre en noir mat, intérieur des logements compris | `black PETG filament` | — |
| Colle chaude ou colle époxy (bloque les photodiodes dans leurs logements) | 1 | `hot glue` | 3 € |
| **Graisse PTFE** (vis sans fin et roues : obligatoire en PETG ; pas les roulements, graissés d'origine) | 1 tube | `PTFE grease` | 8 € |
| Colle cyanoacrylate (optionnel : vis sans fin sur leur arbre, pivots imprimés dans le chapeau) | 1 | `super glue` | 3 € |
| Colle à roulements, type Loctite 641 (seulement si les arbres font moins de 4,98 mm) | 1 | `Loctite 641` | 8–12 € |

## 6. Optionnel

| Article | Qté | Pour quoi |
|---|---|---|
| Lest de 2 à 3 kg (sac de sable, bouteille d'eau) | 1 | Démonstration en extérieur, contre le vent |

---

**Ordre de grandeur total** : environ **100 à 150 €** avec une alimentation secteur, capteur
solaire compris (environ 8 €), sans compter le trépied ni le panneau. Il faut ajouter environ 50 € pour une batterie LiFePO4
destinée à la démonstration en extérieur.

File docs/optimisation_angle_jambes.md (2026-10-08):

# Optimisation de l'angle φ des jambes du trépied

Générée par `scripts/optimisation_angle.py` à partir des masses et centres de gravité de la CAO.

## Données fixées par la tête et le panneau

- Jambes en Y, à 120°. Articulation haute à r = 70 mm, z = 509 mm : juste sous le socle de la tête. Le panneau vertical descend jusqu'à 571 mm et tout le trépied doit rester en dessous.
- Centre de la rotule de pied à z = 40 mm, soit une hauteur de jambe h = 469 mm.
- Tête + panneau : 3.07 kg. Le centre de gravité est pris dans la pire orientation du panneau (élévation de −2° à +92°, azimut sur 360°).

## Exigences

| Exigence | Valeur |
|---|---|
| Pente maxi sans ancrage (C1) | 15° |
| Obstacle ou enfoncement sous un pied (C1) | 50 mm |
| Marge de sécurité au basculement (C1) | 5° |
| Pente rattrapée par les jambes télescopiques (C2) | 10° |
| Recouvrement mini des tubes (C2) | 45 mm |

## Résultats selon φ

| φ | Ø des pieds | Jambe | Masse trépied | Basculement | Exigé (C1) | Course ± nécessaire / possible (C2) | Poussée entretoise | Rigidité latérale | Admissible |
|---|---|---|---|---|---|---|---|---|---|
| 25.0° | 577 mm | 517 mm | 4.24 kg | 19.5° | 26.6° | 56 / 111 mm | 0.47 × charge | 42 % | non (C1) |
| 27.5° | 628 mm | 529 mm | 4.27 kg | 21.2° | 26.1° | 62 / 115 mm | 0.52 × charge | 49 % | non (C1) |
| 30.0° | 682 mm | 542 mm | 4.30 kg | 23.0° | 25.6° | 69 / 119 mm | 0.58 × charge | 56 % | non (C1) |
| 32.5° | 738 mm | 556 mm | 4.33 kg | 24.8° | 25.2° | 77 / 124 mm | 0.64 × charge | 63 % | non (C1) |
| **33.0°** | 749 mm | 559 mm | 4.34 kg | 25.2° | 25.1° | 79 / 125 mm | 0.65 × charge | 65 % | oui |
| 35.0° | 797 mm | 573 mm | 4.37 kg | 26.7° | 24.8° | 86 / 129 mm | 0.70 × charge | 70 % | oui |
| 37.5° | 860 mm | 591 mm | 4.41 kg | 28.7° | 24.4° | 96 / 135 mm | 0.77 × charge | 76 % | oui |
| 40.0° | 927 mm | 612 mm | 4.45 kg | 30.6° | 24.1° | 107 / 142 mm | 0.84 × charge | 82 % | oui |
| 42.5° | 1000 mm | 636 mm | 4.51 kg | 32.7° | 23.8° | 120 / 150 mm | 0.92 × charge | 87 % | oui |
| 45.0° | 1078 mm | 663 mm | 4.56 kg | 34.9° | 23.5° | 134 / 159 mm | 1.00 × charge | 92 % | oui |
| 47.5° | 1164 mm | 694 mm | 4.63 kg | 37.2° | 23.3° | 152 / 170 mm | 1.09 × charge | 95 % | oui |
| 50.0° | 1258 mm | 730 mm | 4.70 kg | 39.6° | 23.0° | 173 / 182 mm | 1.19 × charge | 98 % | non (C3) |
| 52.5° | 1362 mm | 770 mm | 4.79 kg | 42.1° | 22.8° | 197 / 195 mm | 1.30 × charge | 100 % | non (C2, C3) |
| 55.0° | 1480 mm | 818 mm | 4.89 kg | 44.8° | 22.6° | 227 / 211 mm | 1.43 × charge | 100 % | non (C2, C3) |
| 57.5° | 1612 mm | 873 mm | 5.02 kg | 47.6° | 22.4° | 265 / 229 mm | 1.57 × charge | 99 % | non (C2, C3) |
| 60.0° | 1765 mm | 938 mm | 5.17 kg | 50.6° | 22.2° | 311 / 251 mm | 1.73 × charge | 97 % | non (C2, C3) |

**Plage admissible : φ de 33.0° à 49.0°. Optimum : φ = 33.0°**, le plus petit angle admissible, donc les jambes les plus courtes et les plus légères, la poussée la plus faible dans les entretoises, la plus petite course de nivelage et la plus petite emprise au sol.

La rigidité latérale est maximale à 54,7°, mais elle ne dimensionne pas sur la Lune : sans vent, seuls les pas des moteurs et les manipulations l'excitent.

## Sensibilité de l'optimum aux exigences

| Variante | φ optimal |
|---|---|
| Exigences de référence | 33.0° |
| Pente sans ancrage 10° | 27.5° |
| Pente sans ancrage 20° | 38.5° |
| Sans obstacle sous un pied | 26.0° |
| Obstacle de 100 mm | 38.0° |
| Marge de 10° | 38.5° |
| Nivelage sur 15° | 33.0° |

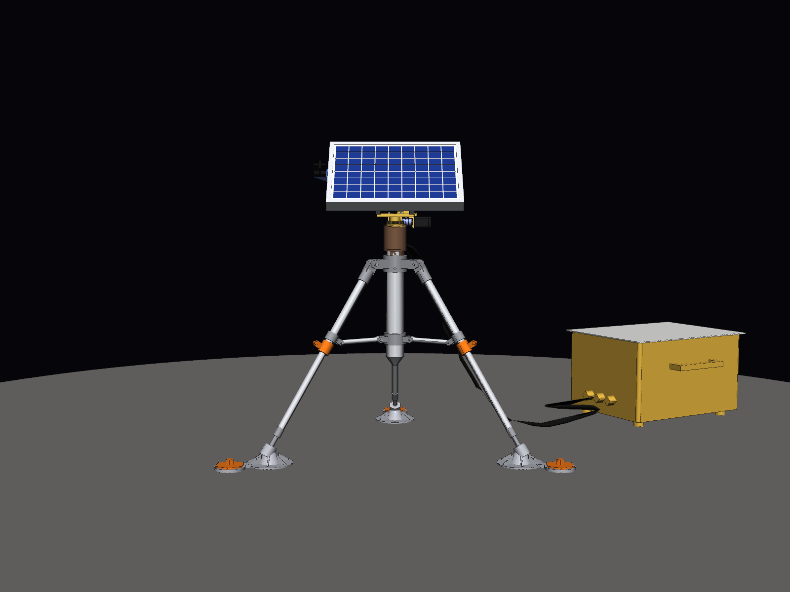
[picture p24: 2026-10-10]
docs/apercu_latitudemoyenne_face.png

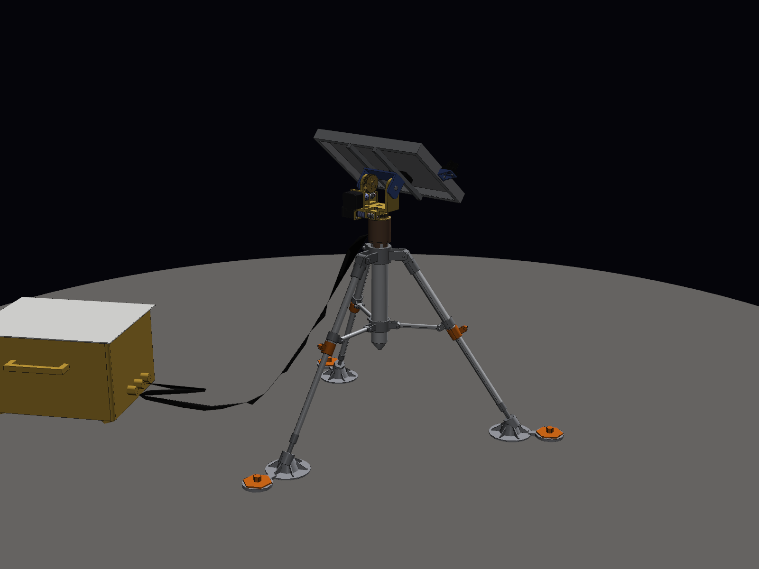
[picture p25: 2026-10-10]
docs/apercu_latitudemoyenne_arriere.png

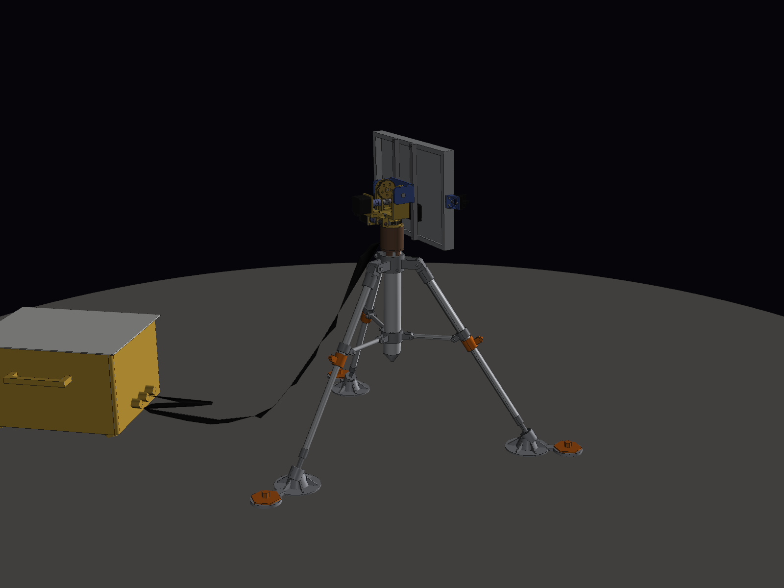
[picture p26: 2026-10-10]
docs/apercu_polesud_arriere.png

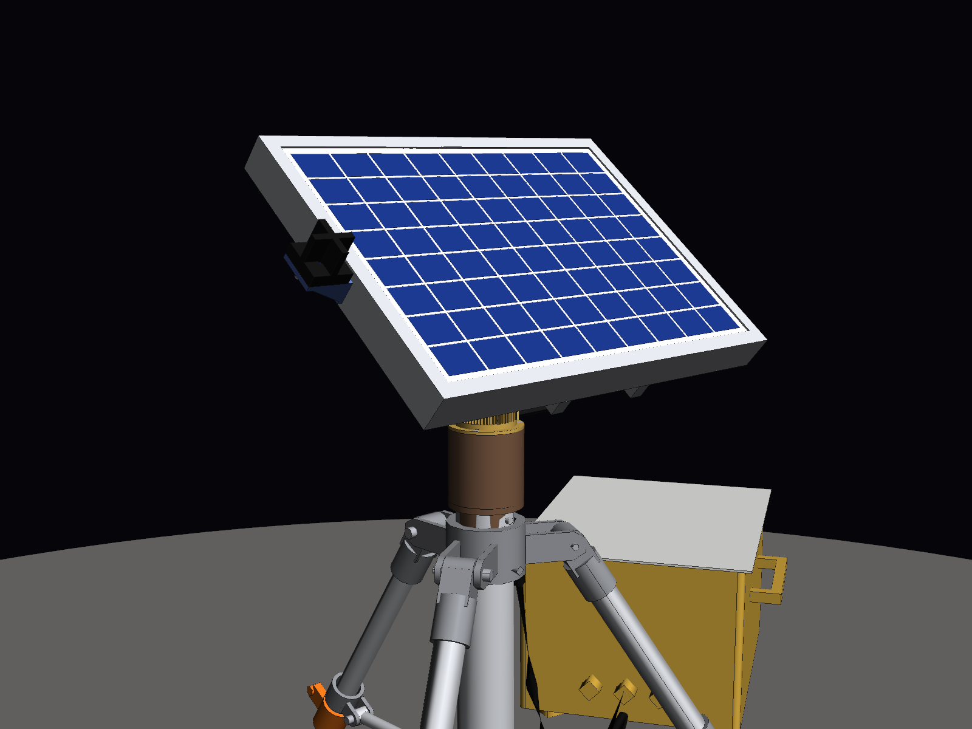
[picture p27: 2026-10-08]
docs/apercu_latitudemoyenne_detail_tete_avant.png

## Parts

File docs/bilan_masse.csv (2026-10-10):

Piece | Quantite | Materiau | Masse totale (kg) | Description
Unite_Controle_Corps | 1 | masse forfaitaire | 17.000 | Unité de contrôle / stockage sous MLI (batterie, ESP32, drivers TMC2209)
Unite_Controle_Radiateur | 1 | Al 6061-T6 | 1.212 | Radiateur zénithal (peinture blanche / OSR)
Ancrage_Helicoidal | 3 | Ti-6Al-4V | 1.020 | Vis d'ancrage hélicoïdale Ø60, 400 mm dans le régolithe
Patin | 3 | Al 7075-T73 | 0.931 | Patin Ø120 à crampons + logement de rotule
Lamine_PV | 1 | masse forfaitaire | 0.850 | Verre + EVA + face arrière
Collier_Superieur | 1 | Ti-6Al-4V | 0.441 | Moyeu d'articulation des jambes
Ferrure_Jambe | 3 | Ti-6Al-4V | 0.402 | Ferrure d'articulation de jambe
Chape | 1 | Al 6061-T6 | 0.326 | Chape en U (tourne en azimut, porte les moteurs)
Faisceau_Cables | 1 | PTFE/cuivre (eq) | 0.275 | Faisceau puissance + données Ø12
Tube_Jambe_Inferieur | 3 | Al 7075-T73 | 0.265 | Tube coulissant Ø20x1,5
Colonne_Centrale | 1 | Al 7075-T73 | 0.261 | Colonne centrale Ø50x2 anodisée dur
Cadre_Panneau | 1 | Al 6063-T5 | 0.246 | Cadre alu du panneau 356x253x30
Embout_Rotule | 3 | Ti-6Al-4V | 0.220 | Embout à rotule Ø22
Moteur_Elevation_NEMA17 | 1 | masse forfaitaire | 0.220 | Moteur pas à pas d'élévation : NEMA 17 42 x 42 x 34 mm (17HS3401 Usongshine, 0,34 N·m, 1,0 A)
Tube_Jambe_Superieur | 3 | Al 7075-T73 | 0.215 | Tube Ø25x1,5 anodisé dur
Rail_Panneau | 2 | Al 6061-T6 | 0.209 | Rail 12 x 13 vissé sur le cadre du panneau
Bague_Blocage | 3 | Ti-6Al-4V | 0.198 | Bague de blocage télescopique
Moteur_Azimut_NEMA11 | 1 | masse forfaitaire | 0.180 | Moteur pas à pas d'azimut : NEMA 11 28 x 28 x 45 mm (11HS18-0674S, 0,10 N·m, 0,67 A)
Collier_Inferieur | 1 | Ti-6Al-4V | 0.161 | Collier coulissant des entretoises
Chapeau_U | 1 | Al 6061-T6 | 0.146 | Chapeau en U renversé porte-panneau
Socle | 1 | Al 6061-T6 | 0.134 | Socle Ø62 : roulements d'azimut, passe-câble
Roue_Elevation | 1 | Bronze CuSn12 | 0.125 | Roue d'élévation m1 Z50
Bride_Entretoise | 3 | Ti-6Al-4V | 0.117 | Bride de fixation d'entretoise
Roue_Azimut_Fixe | 1 | Bronze CuSn12 | 0.103 | Roue d'azimut m0,8 Z60, fixée sur le socle
Roulement_6806 | 2 | Acier 440C | 0.071 | Roulement d'azimut 6806 (61806) 30 x 42 x 7, protégé ZZ (ou 2RS)
Entretoise | 3 | Al 7075-T73 | 0.066 | Entretoise Ø12x1
Fond_Socle | 1 | Al 6061-T6 | 0.064 | Fond du socle, centrage dans la colonne
Boite_Jonction | 1 | PPO (boîte de jonction) | 0.043 | Boîte de jonction + presse-étoupe
Capteur_Solaire_Boitier | 1 | Al 6061-T6 | 0.038 | Capteur solaire : boîtier noir, 4 photodiodes BPW34 sous une croix d'ombre de 20 mm (anodisé noir)
Accouplement | 2 | Al 7075-T73 | 0.036 | Accouplement flexible 5/5
Roulement_608 | 2 | Acier 440C | 0.034 | Roulement d'élévation 608 8 x 22 x 7, protégé ZZ (ou 2RS)
Support_Moteur_Elevation | 1 | Al 6061-T6 | 0.031 | Support du moteur d'élévation
Vis_Elevation | 1 | Acier inox 17-4PH | 0.024 | Vis sans fin d'élévation m1 Ø16, un filet
Cellules_PV | 1 | Silicium polycristallin | 0.022 | 72 cellules 33.8x25.4
Axe_Articulation | 3 | Ti-6Al-4V | 0.021 | Axe Ø6 revêtu MoS2
Axe_Entretoise | 6 | Ti-6Al-4V | 0.021 | Axe Ø5
Capteur_Solaire_Support | 1 | Al 6061-T6 | 0.017 | Équerre du capteur solaire, vissée sur le petit côté du cadre (2 x M3, écrous dans le cadre)
Palier_Vis_Elevation | 1 | Al 6061-T6 | 0.017 | Palier de la vis d'élévation
Vis_Azimut | 1 | Acier inox 17-4PH | 0.016 | Vis sans fin d'azimut m0,8 Ø12, un filet
Palier_Vis_Azimut | 1 | Al 6061-T6 | 0.015 | Palier de la vis d'azimut
Pivot_Entraine | 1 | Acier inox 17-4PH | 0.014 | Pivot Ø8 portant la roue d'élévation
Bague_Arret_Moyeu | 1 | Acier inox 17-4PH | 0.012 | Rondelle d'arrêt du moyeu (2 x M3)
Roulement_685 | 4 | Acier 440C | 0.011 | Roulement 685ZZ (ou 685-2RS) 5 x 11 x 5 (arbres des vis ; le 685 ouvert ne fait que 3 mm)
Support_Moteur_Azimut | 1 | Al 6061-T6 | 0.010 | Support du moteur d'azimut
Vis_CHC_M3x14 | 8 | Acier (visserie) | 0.008 | Vis CHC M3x14 (ISO 4762)
Pivot_Libre | 1 | Acier inox 17-4PH | 0.008 | Pivot Ø8 libre
Arbre_Vis_Azimut | 1 | Acier inox 17-4PH | 0.008 | Arbre Ø5 de la vis d'azimut
Arbre_Vis_Elevation | 1 | Acier inox 17-4PH | 0.008 | Arbre Ø5 de la vis d'élévation
Vis_CHC_M3x12 | 8 | Acier (visserie) | 0.008 | Vis CHC M3x12 (ISO 4762)
Vis_CHC_M3x8 | 6 | Acier (visserie) | 0.005 | Vis CHC M3x8 (ISO 4762)
Vis_CHC_M3x25 | 3 | Acier (visserie) | 0.004 | Vis CHC M3x25 (ISO 4762)
Vis_CHC_M3x10 | 4 | Acier (visserie) | 0.004 | Vis CHC M3x10 (ISO 4762)
Ecrou_M3 | 6 | Acier (visserie) | 0.002 | Écrou M3 (ISO 4032)
Vis_CHC_M2.5x6 | 4 | Acier (visserie) | 0.002 | Vis CHC M2,5x6 (ISO 4762)
Vis_FHC_M3x8 | 3 | Acier (visserie) | 0.001 | Vis à tête fraisée M3x8 (ISO 10642)
Vis_CHC_M3x6 | 1 | Acier (visserie) | 0.001 | Vis CHC M3x6 (ISO 4762)
Rondelle_M3 | 4 | Acier (visserie) | 0.000 | Rondelle M3 (ISO 7089), 3,2 x 7 x 0,5
Photodiode_BPW34 | 4 | Époxy transparent + silicium | 0.000 | Photodiode BPW34 (Vishay), surface sensible 7,5 mm²
TOTAL |  |  | 25.90

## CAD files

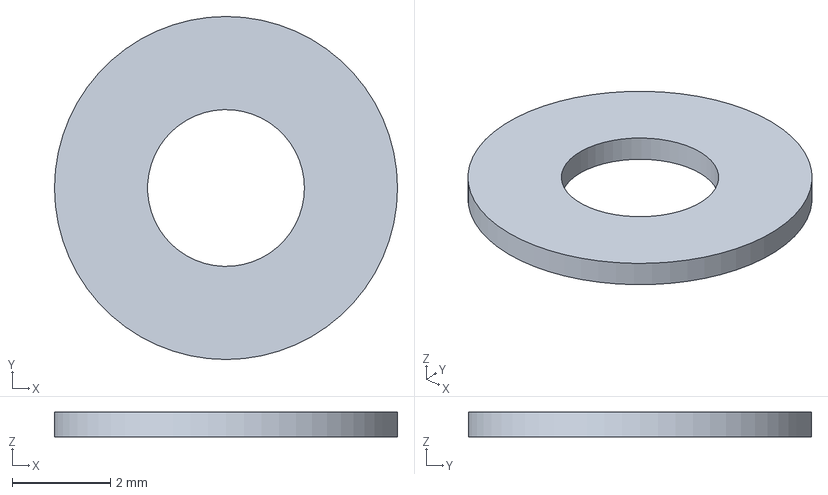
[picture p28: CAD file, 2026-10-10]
CAO/Cas_Reel/pieces/Rondelle_M3.step
7.00 x 7.00 x 0.5 mm

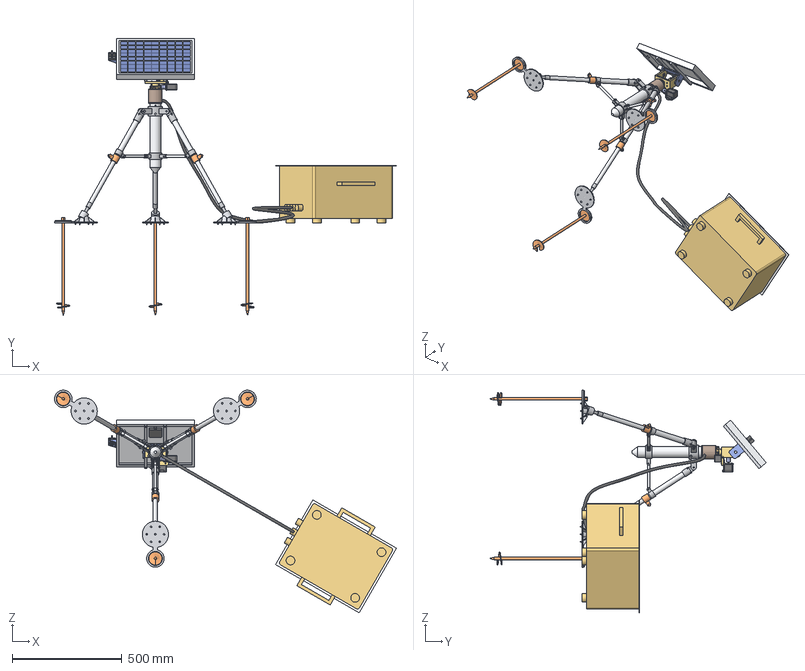
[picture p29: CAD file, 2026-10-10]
CAO/Cas_Reel/Tracker_Lunaire_LatitudeMoyenne.step
1557.9 x 1259.5 x 1014.4 mm
Colonne_Centrale
Collier_Superieur
Collier_Inferieur
Ferrure_Jambe x 3
Axe_Articulation x 3
Tube_Jambe_Superieur x 3
Bague_Blocage x 3
Tube_Jambe_Inferieur x 3
Embout_Rotule x 3
Bride_Entretoise x 3
Patin x 3
Ancrage_Helicoidal x 3
Entretoise x 3
Axe_Entretoise x 6
Fond_Socle
Socle
Roulement_6806 x 2
Roue_Azimut_Fixe
Vis_CHC_M3x25 x 3
Vis_FHC_M3x8 x 3
Vis_CHC_M3x6
Chape
Bague_Arret_Moyeu
Roulement_608 x 2
Palier_Vis_Azimut
Arbre_Vis_Azimut
Roulement_685 x 4
Vis_Azimut
Accouplement x 2
Support_Moteur_Azimut
Moteur_Azimut_NEMA11
Palier_Vis_Elevation
Arbre_Vis_Elevation
Vis_Elevation
Support_Moteur_Elevation
Moteur_Elevation_NEMA17
Vis_CHC_M3x8 x 6
Vis_CHC_M3x12 x 8
Vis_CHC_M2.5x6 x 4
Rondelle_M3 x 4
Chapeau_U
Pivot_Entraine
Pivot_Libre
Roue_Elevation
Rail_Panneau x 2
Vis_CHC_M3x14 x 8
Cadre_Panneau
Lamine_PV
Cellules_PV
Boite_Jonction
Vis_CHC_M3x10 x 4
Ecrou_M3 x 6
Capteur_Solaire_Support
Capteur_Solaire_Boitier
Photodiode_BPW34 x 4
Unite_Controle_Corps
Unite_Controle_Radiateur
Faisceau_Cables

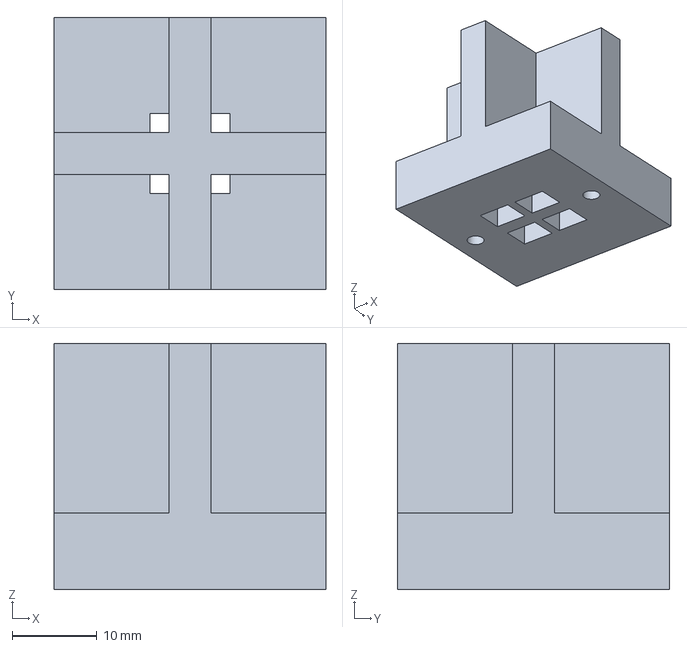
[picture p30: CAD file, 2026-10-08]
CAO/Demo_Terre_PETG/a_imprimer/Capteur_Solaire_Boitier.step
32.0 x 32.0 x 29.0 mm

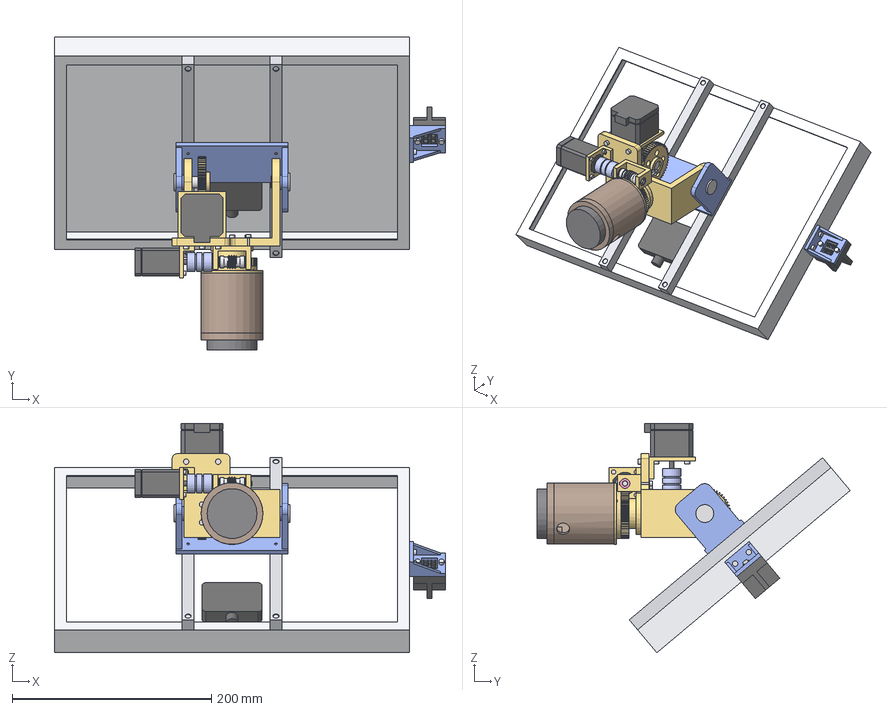
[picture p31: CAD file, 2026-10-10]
CAO/Demo_Terre_PETG/Tete_Rotative_PETG.step
392.0 x 314.2 x 230.0 mm
Plateau_Trepied_Photo
Fond_Socle
Ecrou_1_4_UNC
Socle
Roulement_6806 x 2
Roue_Azimut_Fixe
Vis_CHC_M3x10 x 7
Vis_FHC_M3x8 x 3
Chape
Moyeu_Chape
Bague_Arret_Moyeu
Roulement_6801 x 2
Palier_Vis_Azimut
Arbre_Vis_Azimut
Roulement_685 x 4
Vis_Azimut
Accouplement x 2
Support_Moteur_Azimut
Moteur_Azimut_NEMA11
Palier_Vis_Elevation
Arbre_Vis_Elevation
Vis_Elevation
Support_Moteur_Elevation
Moteur_Elevation_NEMA17
Vis_CHC_M3x8 x 6
Vis_CHC_M3x12 x 11
Vis_CHC_M2.5x6 x 4
Rondelle_M3 x 4
Chapeau_U
Pivot_Entraine
Pivot_Libre
Roue_Elevation
Rail_Panneau x 2
Vis_CHC_M3x14 x 8
Cadre_Panneau
Lamine_PV
Cellules_PV
Boite_Jonction
Ecrou_M3 x 6
Capteur_Solaire_Support
Capteur_Solaire_Boitier
Photodiode_BPW34 x 4

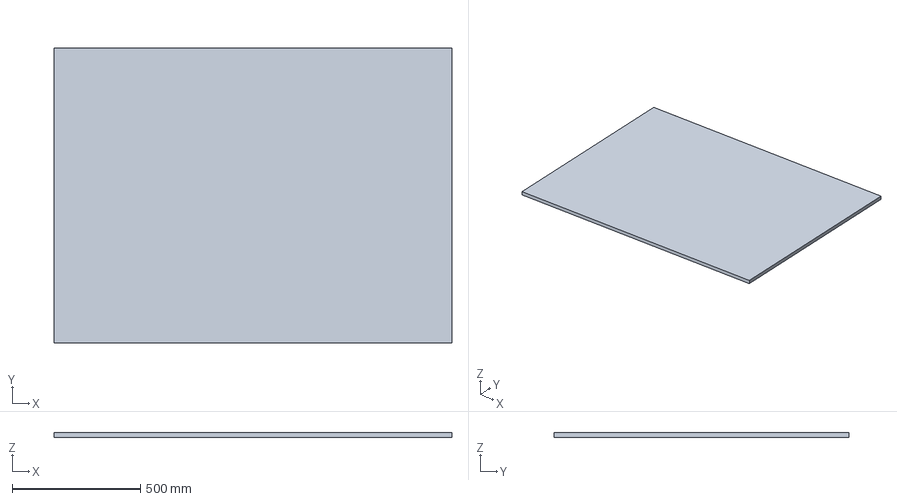
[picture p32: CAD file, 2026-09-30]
CAO/pieces/Substrat_Panneau.step
1550.0 x 1150.0 x 20.0 mm

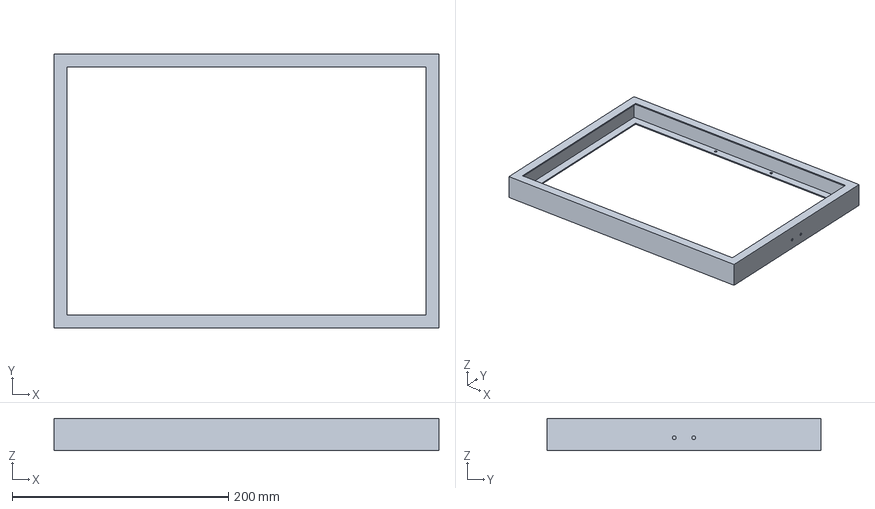
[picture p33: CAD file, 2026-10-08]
CAO/Cas_Reel/pieces/Cadre_Panneau.step
356.0 x 253.0 x 30.0 mm

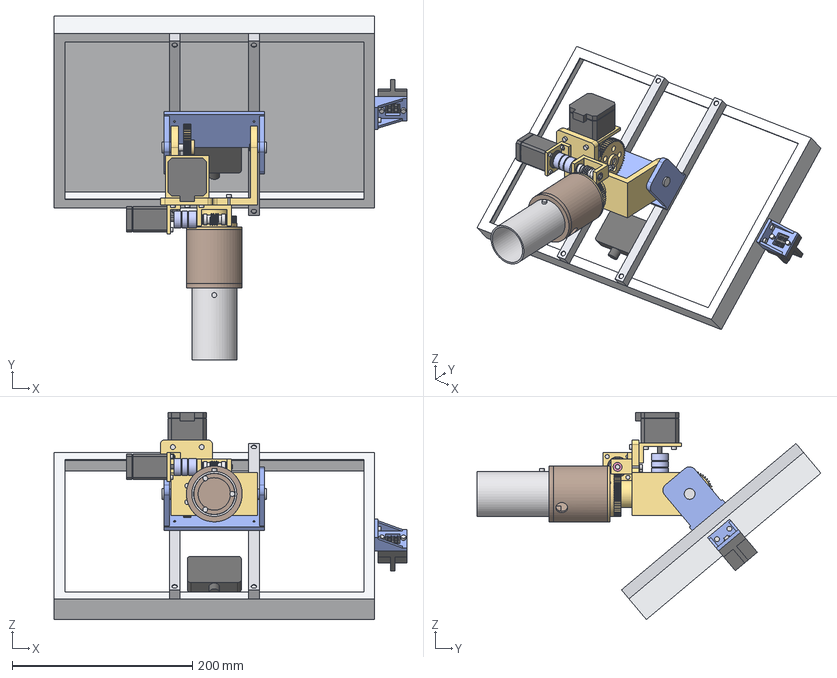
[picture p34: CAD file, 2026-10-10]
CAO/Cas_Reel/Tete_Rotative_VisSansFin.step
392.0 x 381.8 x 230.0 mm
Haut_Colonne_Trepied
Fond_Socle
Socle
Roulement_6806 x 2
Roue_Azimut_Fixe
Vis_CHC_M3x25 x 3
Vis_FHC_M3x8 x 3
Vis_CHC_M3x6
Chape
Bague_Arret_Moyeu
Roulement_608 x 2
Palier_Vis_Azimut
Arbre_Vis_Azimut
Roulement_685 x 4
Vis_Azimut
Accouplement x 2
Support_Moteur_Azimut
Moteur_Azimut_NEMA11
Palier_Vis_Elevation
Arbre_Vis_Elevation
Vis_Elevation
Support_Moteur_Elevation
Moteur_Elevation_NEMA17
Vis_CHC_M3x8 x 6
Vis_CHC_M3x12 x 8
Vis_CHC_M2.5x6 x 4
Rondelle_M3 x 4
Chapeau_U
Pivot_Entraine
Pivot_Libre
Roue_Elevation
Rail_Panneau x 2
Vis_CHC_M3x14 x 8
Cadre_Panneau
Lamine_PV
Cellules_PV
Boite_Jonction
Vis_CHC_M3x10 x 4
Ecrou_M3 x 6
Capteur_Solaire_Support
Capteur_Solaire_Boitier
Photodiode_BPW34 x 4

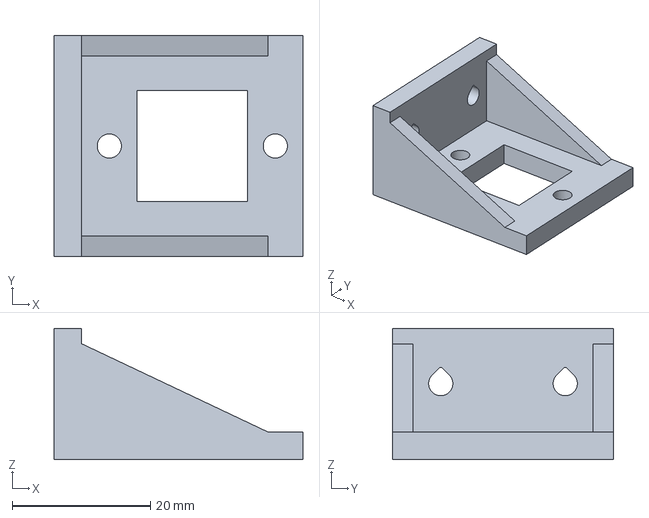
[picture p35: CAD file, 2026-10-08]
CAO/Demo_Terre_PETG/a_imprimer/Capteur_Solaire_Support.step
36.0 x 32.0 x 19.0 mm

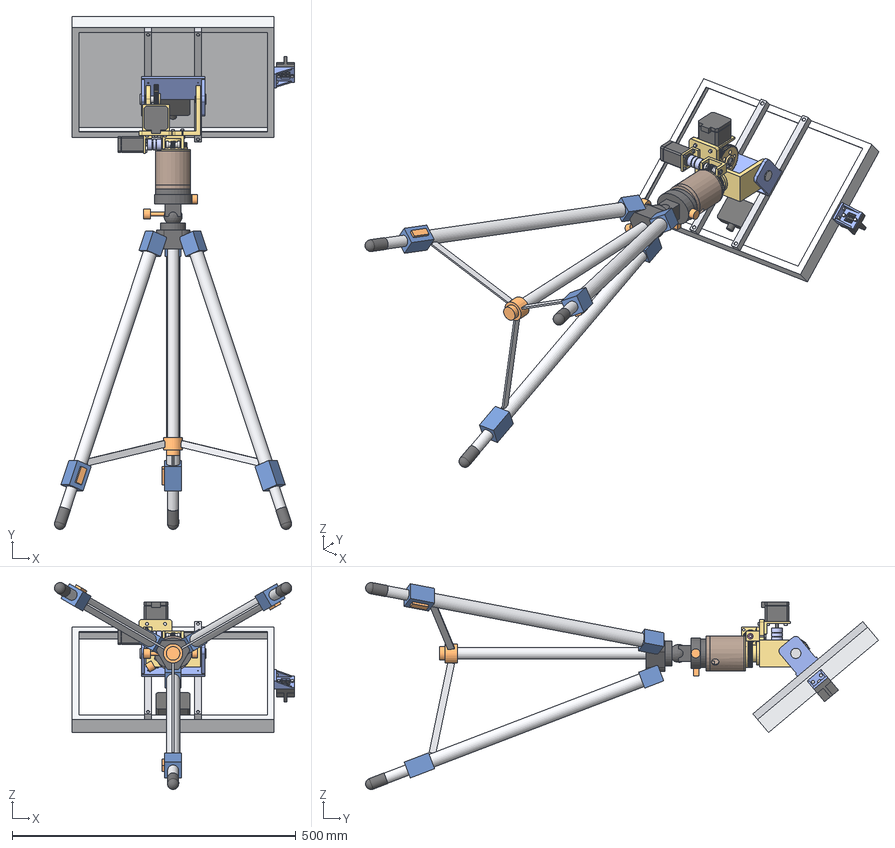
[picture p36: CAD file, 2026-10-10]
CAO/Demo_Terre_PETG/Demo_Trepied.step
423.0 x 904.2 x 365.0 mm
Trepied_Photo_Corps
Trepied_Photo_Rotule
Trepied_Photo_Plateau
Trepied_Photo_Vis_1_4
Trepied_Photo_Molettes
Trepied_Photo_Colonne
Trepied_Photo_Moyeu
Trepied_Photo_Charniere_1
Trepied_Photo_Tube_Haut_1
Trepied_Photo_Verrou_1
Trepied_Photo_Clip_1
Trepied_Photo_Tube_Bas_1
Trepied_Photo_Embout_1
Trepied_Photo_Entretoise_1
Trepied_Photo_Charniere_2
Trepied_Photo_Tube_Haut_2
Trepied_Photo_Verrou_2
Trepied_Photo_Clip_2
Trepied_Photo_Tube_Bas_2
Trepied_Photo_Embout_2
Trepied_Photo_Entretoise_2
Trepied_Photo_Charniere_3
Trepied_Photo_Tube_Haut_3
Trepied_Photo_Verrou_3
Trepied_Photo_Clip_3
Trepied_Photo_Tube_Bas_3
Trepied_Photo_Embout_3
Trepied_Photo_Entretoise_3
Fond_Socle
Ecrou_1_4_UNC
Socle
Roulement_6806 x 2
Roue_Azimut_Fixe
Vis_CHC_M3x10 x 7
Vis_FHC_M3x8 x 3
Chape
Moyeu_Chape
Bague_Arret_Moyeu
Roulement_6801 x 2
Palier_Vis_Azimut
Arbre_Vis_Azimut
Roulement_685 x 4
Vis_Azimut
Accouplement x 2
Support_Moteur_Azimut
Moteur_Azimut_NEMA11
Palier_Vis_Elevation
Arbre_Vis_Elevation
Vis_Elevation
Support_Moteur_Elevation
Moteur_Elevation_NEMA17
Vis_CHC_M3x8 x 6
Vis_CHC_M3x12 x 11
Vis_CHC_M2.5x6 x 4
Rondelle_M3 x 4
Chapeau_U
Pivot_Entraine
Pivot_Libre
Roue_Elevation
Rail_Panneau x 2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

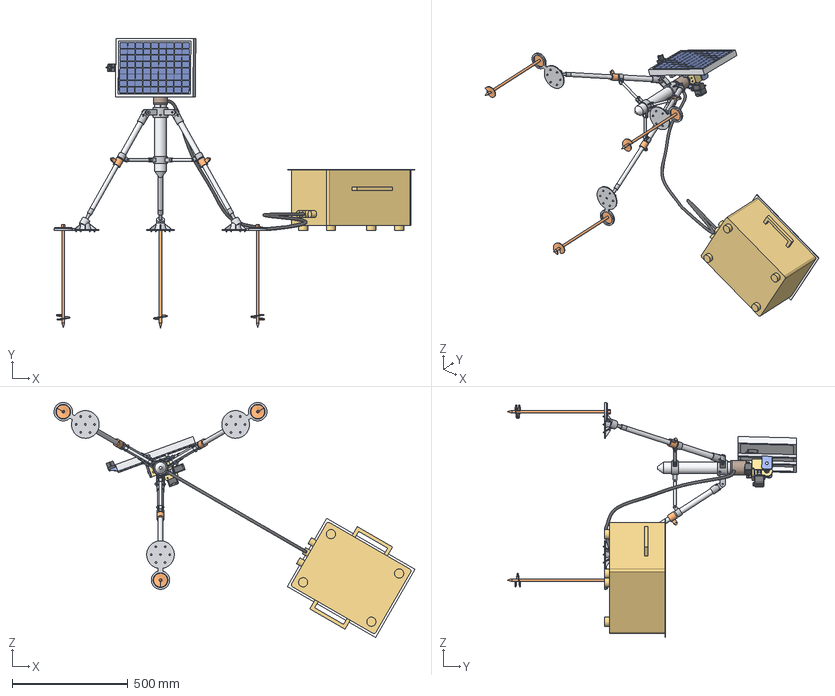
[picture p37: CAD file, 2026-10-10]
CAO/Cas_Reel/Tracker_Lunaire_PoleSud.step
1557.9 x 1248.4 x 1014.4 mm
Colonne_Centrale
Collier_Superieur
Collier_Inferieur
Ferrure_Jambe x 3
Axe_Articulation x 3
Tube_Jambe_Superieur x 3
Bague_Blocage x 3
Tube_Jambe_Inferieur x 3
Embout_Rotule x 3
Bride_Entretoise x 3
Patin x 3
Ancrage_Helicoidal x 3
Entretoise x 3
Axe_Entretoise x 6
Fond_Socle
Socle
Roulement_6806 x 2
Roue_Azimut_Fixe
Vis_CHC_M3x25 x 3
Vis_FHC_M3x8 x 3
Vis_CHC_M3x6
Chape
Bague_Arret_Moyeu
Roulement_608 x 2
Palier_Vis_Azimut
Arbre_Vis_Azimut
Roulement_685 x 4
Vis_Azimut
Accouplement x 2
Support_Moteur_Azimut
Moteur_Azimut_NEMA11
Palier_Vis_Elevation
Arbre_Vis_Elevation
Vis_Elevation
Support_Moteur_Elevation
Moteur_Elevation_NEMA17
Vis_CHC_M3x8 x 6
Vis_CHC_M3x12 x 8
Vis_CHC_M2.5x6 x 4
Rondelle_M3 x 4
Chapeau_U
Pivot_Entraine
Pivot_Libre
Roue_Elevation
Rail_Panneau x 2
Vis_CHC_M3x14 x 8
Cadre_Panneau
Lamine_PV
Cellules_PV
Boite_Jonction
Vis_CHC_M3x10 x 4
Ecrou_M3 x 6
Capteur_Solaire_Support
Capteur_Solaire_Boitier
Photodiode_BPW34 x 4
Unite_Controle_Corps
Unite_Controle_Radiateur
Faisceau_Cables

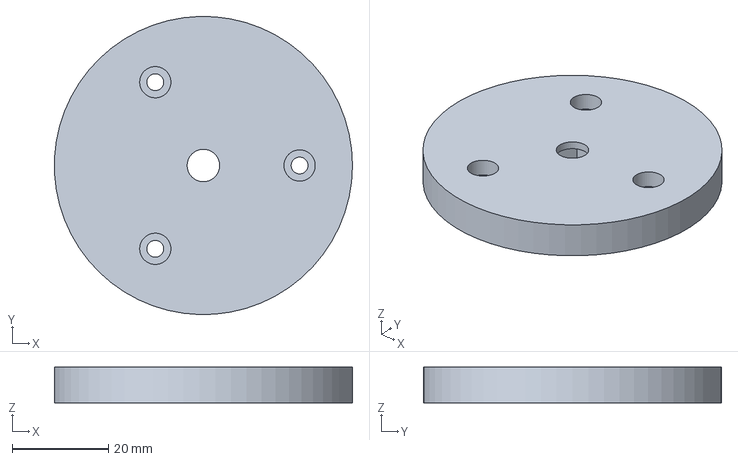
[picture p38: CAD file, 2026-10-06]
CAO/Demo_Terre_PETG/a_imprimer/Fond_Socle.step
62.0 x 62.0 x 7.40 mm

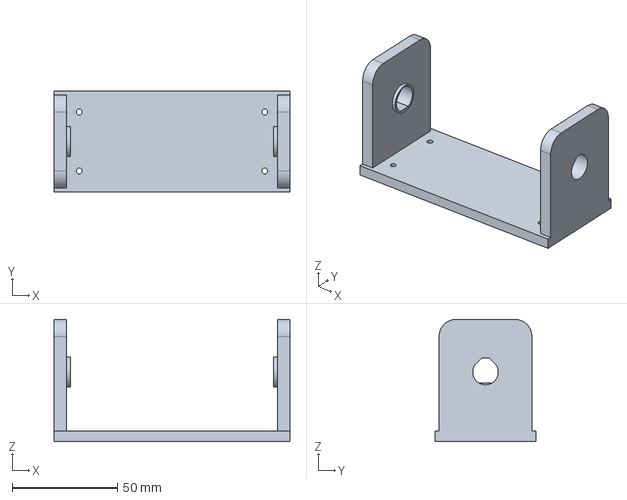
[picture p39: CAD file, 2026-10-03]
CAO/Demo_Terre_PETG/a_imprimer/Chapeau_U.step
112.0 x 48.0 x 58.0 mm

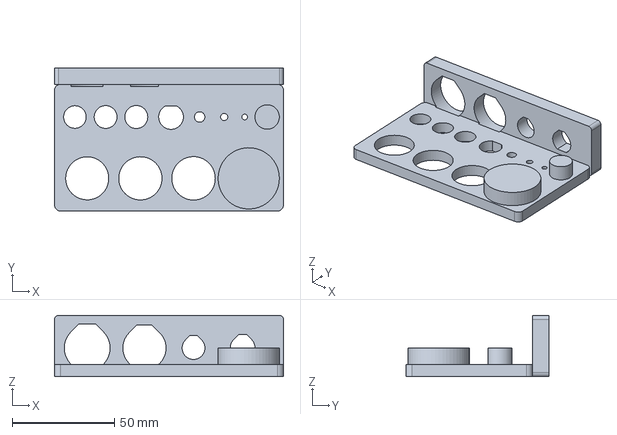
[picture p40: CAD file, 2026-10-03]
CAO/Demo_Terre_PETG/Eprouvette_Ajustements.step
112.0 x 70.0 x 30.0 mm

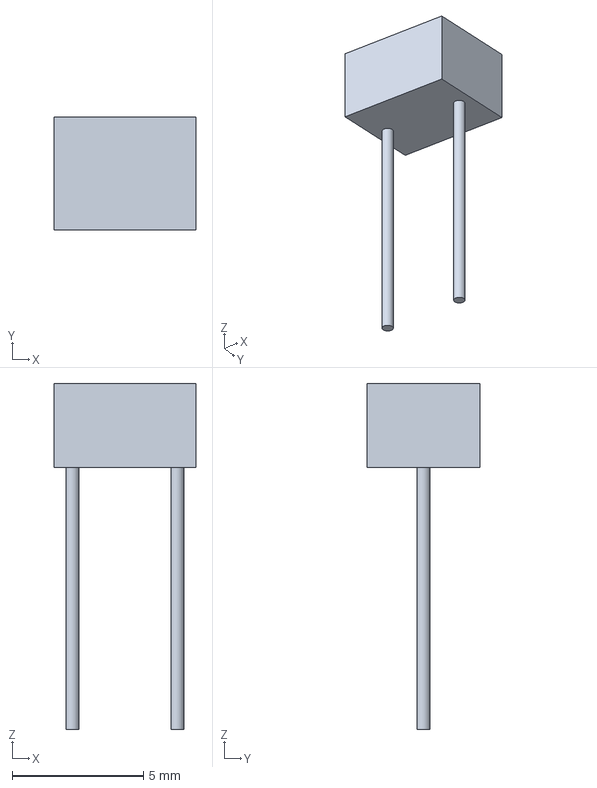
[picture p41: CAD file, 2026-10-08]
CAO/Cas_Reel/pieces/Photodiode_BPW34.step
5.40 x 4.30 x 13.2 mm

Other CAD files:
CAO/Cas_Reel/pieces/Capteur_Solaire_Support.step
CAO/Demo_Terre_PETG/Demo_Trepied_Dexter.step
CAO/Cas_Reel/pieces/Capteur_Solaire_Boitier.step
CAO/Demo_Terre_PETG/a_imprimer/Support_Moteur_Elevation.step
CAO/Cas_Reel/pieces/Accouplement.step
CAO/Cas_Reel/pieces/Ancrage_Helicoidal.step
CAO/Cas_Reel/pieces/Arbre_Vis_Azimut.step
CAO/Cas_Reel/pieces/Arbre_Vis_Elevation.step
CAO/Cas_Reel/pieces/Axe_Articulation.step
CAO/Cas_Reel/pieces/Axe_Entretoise.step
CAO/Cas_Reel/pieces/Bague_Arret_Moyeu.step
CAO/Cas_Reel/pieces/Bague_Blocage.step
CAO/Cas_Reel/pieces/Boite_Jonction.step
CAO/Cas_Reel/pieces/Bride_Entretoise.step
CAO/Cas_Reel/pieces/Cellules_PV.step
CAO/Cas_Reel/pieces/Chape.step
CAO/Cas_Reel/pieces/Chapeau_U.step
CAO/Cas_Reel/pieces/Collier_Inferieur.step
CAO/Cas_Reel/pieces/Collier_Superieur.step
CAO/Cas_Reel/pieces/Colonne_Centrale.step
CAO/Cas_Reel/pieces/Ecrou_M3.step
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

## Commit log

2026-09-30 Ajout de la CAO 1:1 d'un tracker solaire lunaire deux axes
    Assemblage STEP AP214 (ouvrable dans SolidWorks) d'un tracker azimut/élévation
    sur trépied déployable, dans deux poses : pôle Sud (panneau quasi vertical) et
    latitude moyenne (panneau à 40°). Inclut les 29 pièces seules, le script
    paramétrique CadQuery de génération (bilan de masse, contrôle d'interférences
    et de garde sur toute la plage de mouvement), des rendus d'aperçu et une note
    de conception détaillant les choix liés aux conditions lunaires.
    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
    [Axe_Articulation.step, Axe_Entretoise.step, Bague_Blocage.step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]
2026-09-30 Tête mécanique à engrenages et panneau 356 x 253 x 30 mm
    Remplace l'ancien panneau de 1,6 x 1,2 m et ses actionneurs par :
    - le panneau fourni (356 x 253 x 30, cadre alu en C, 72 cellules,
    boîte de jonction) monté sur un berceau et deux rails ;
    - une tête de type tourelle à engrenages : embase, roulement et couronne
    d'azimut Z120 m1,5 entraînée par un NEMA 17 à axe vertical (Y), étrier
    en U portant un NEMA 17 à axe horizontal (X) qui entraîne la roue
    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
    [Arbre_Elevation.step, Axe_Articulation.step, Axe_Entretoise.step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]
2026-09-30 Trépied redimensionné pour le panneau 356 x 253 et vis d'ancrage
    Le trépied est désormais paramétré et dimensionné pour la nouvelle tête :
    axe d'élévation à 700 mm (point bas du panneau vertical à 571 mm), moyeu
    des jambes à 480 mm, pieds sur Ø960 (écartement 43°), tubes Ø25/Ø20,
    entretoises Ø12, colonne Ø50, patins Ø120 à rotule. Les piquets lisses
    sont remplacés par des vis d'ancrage hélicoïdales Ø60 à 400 mm (le
    frottement est six fois plus faible sur la Lune).
    Tracker : 9,4 kg (au lieu de 18,1), centre de gravité à 0,39 m,
    basculement sans ancrage à 30,8°. Aucune interférence dans les deux poses.
    Cl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
    [Ancrage_Helicoidal.step, Arbre_Elevation.step, Axe_Articulation.step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]
2026-09-30 Angle des jambes optimisé (φ = 37°) et script d'optimisation
    optimisation_angle.py évalue φ de 25° à 60° avec les masses et le centre de
    gravité de la CAO (pire orientation du panneau) sous trois contraintes :
    stabilité sans ancrage (pente 15°, obstacle 50 mm, marge 5°), mise à niveau
    sur 10° avec des jambes à deux tubes, et garde au sol de la colonne. Tous les
    autres critères se dégradent avec φ : l'optimum est le plus petit angle
    admissible, 37° (plage 37° à 46°). Rapport et sensibilité dans
    docs/optimisation_angle_jambes.md.
    La géométrie des jambes est désormais pilotée par φ : rayon des pieds,
    course télescopique (±89 mm), bride d'entretoise au-dessus de la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
    [Ancrage_Helicoidal.step, Arbre_Elevation.step, Axe_Articulation.step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]
2026-10-03 Tête rotative à deux moteurs 28BYJ-48 (étude à part)
    Nouveau fichier séparé du tracker : tête pan-tilt posée sur la colonne Ø50
    du trépied, avec ou sans le panneau 356 x 253 x 30.
    - Azimut : 28BYJ-48 fixe dans le socle Ø62, arbre vers le haut sur l'axe
    (corps décalé de 8 mm), chape portée par deux roulements 6806, arbre
    moteur accouplé par méplats (n'entraîne que la rotation).
    - Élévation : 28BYJ-48 logé dans la chape sous l'axe, vis sans fin m1 Ø16
    et roue Z50 (50:1, irréversible), axe Ø8 sur deux roulements 608 ;
    panneau sur platine, rails et demi-tambours.
    Couple vérifié sur la CAO : marge x4 à x5 sur la Lune ; sur Terre, une
    compensation de pesanteur est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
    [Axe_Elevation.step, Bague_Arret_Moyeu.step, Bague_Axe.step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]
2026-10-03 Tête 28BYJ-48 : élévation en prise directe par un U renversé
    Remplace la vis sans fin par la solution du schéma : un U renversé coiffe
    la chape en U et pivote sur deux axes Ø8 (roulements 608) ; le 28BYJ-48
    est vissé dans la chape contre le bras gauche et son arbre entraîne
    directement le pivot par une empreinte à méplats (l'arbre ne porte rien).
    Le 28BYJ-48 étant trop faible pour un panneau décalé, la partie basculante
    est équilibrée par deux contrepoids en tungstène (2 x 374 g) au bas des
    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
    [Axe_Elevation.step, Bague_Arret_Moyeu.step, Bague_Axe.step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]
2026-10-03 Tête motorisée sans contrepoids : version vis sans fin et version engrenages droits
    Deux fichiers STEP à part, même structure (socle, chape en U, chapeau en U renversé) :
    - vis sans fin : NEMA 17 34 mm + vis m1 / roue Z50 en élévation, NEMA 11 45 mm +
    vis m0,8 / roue fixe Z60 en azimut ; irréversible sur les deux axes
    - engrenages droits : NEMA 17 40 mm + pignon Z15 / secteur Z120 m0,8 en élévation,
    NEMA 17 34 mm + pignon Z18 / couronne fixe Z92 m0,8 en azimut
    Le script calcule les couples (Lune, Terre intérieur, Terre avec vent de 10 m/s),
    cale les dentures, vérifie interférences, engrènement et garde sur toute la course.
    Rendus, README § 12 réécrit ; l'étude 28BYJ-48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
    [Accouplement.step, Arbre_Vis_Azimut.step, Arbre_Vis_Elevation.step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]
2026-10-03 Tracker équipé de la tête rotative à vis sans fin
    - generate_tracker.py : l'ancienne tête est remplacée par la tête à vis sans fin
    (socle Ø62 sur la colonne, chape en U, chapeau en U renversé ; NEMA 17 34 mm +
    vis m1 / roue Z50 en élévation, NEMA 11 45 mm + vis m0,8 / roue fixe Z60 en
    azimut, irréversibles). Panneau à 46 mm de l'axe, faisceau sorti du socle.
    - Angle des jambes réoptimisé avec la tête plus légère : φ = 32°.
    - Union du filet de la vis corrigée (le noyau de la vis d'azimut manquait).
    - generate_tete_vis_sans_fin.py / render_tete_vis_sans_fin.py : tête seule,
    calage des vis, couples, tenue moteurs coupés, rendus.
    - Version à engrenages droits sup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
    [Accouplement.step, Ancrage_Helicoidal.step, Arbre_Elevation.step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]
2026-10-03 Balayage complet de garde : calcul de distance minimum seul (×50 plus rapide)
    BRepExtrema limité au minimum et multithreadé : le contrôle --balayage passe
    d'une durée indéfinie à 11 min. README § 9 complété avec ses résultats.
    Claude-Session: https://claude.ai/code/session_016qGFaGRdDEyZRcESre1E3T
    [Accouplement.step, Ancrage_Helicoidal.step, Arbre_Vis_Azimut.step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]
2026-10-03 Version de démonstration imprimée en PETG, avec jeux d'ajustement
    - generate_tracker.py : deux jeux de cotes pour la tête (AJUSTEMENTS "reel" / "petg") :
    logements de roulements, alésages d'axes, avant-trous, jeux de denture, filets et
    entraxes adaptés à l'impression ; moyeu de chape séparé, vis à moyeux, axes en D,
    cône sous le logement du socle.
    - Fixations complétées et vérifiées : toutes les vis sont modélisées (tête + noyau) et
    passent le contrôle d'interférences. Roue d'azimut posée à plat et tenue par 3 vis
    fraisées sous le passage de la vis ; vis du fond par l'intérieur de la colonne ; vis
    anti-rotation ; palier et support d'azimut vissés par-dessu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
    [Accouplement.step, Ancrage_Helicoidal.step, Arbre_Vis_Azimut.step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]
2026-10-03 Roulements en gris dans les fichiers 3D, références et dimensions
    - Couleur grise dédiée aux roulements (6806, 608, 685) dans tous les assemblages.
    - Désignations complètes dans le bilan de masse : 6806 (61806) 30x42x7,
    608 8x22x7, 685ZZ/2RS 5x11x5.
    - README : tableau des roulements (référence, dimensions, quantité, emplacement)
    et liste d'achat précisée (le 685 ouvert ne fait que 3 mm de large).
    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
    [Accouplement.step, Ancrage_Helicoidal.step, Arbre_Vis_Azimut.step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]
2026-10-03 Roulements en rose dans les fichiers 3D et les aperçus
    - Couleur rose pour tous les roulements (6806, 608, 685) dans les assemblages STEP
    (tracker, tête réelle, tête PETG).
    - Aperçus régénérés, et nouvelle coupe par les axes qui montre les 6806 et les 608.
    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
    [Accouplement.step, Ancrage_Helicoidal.step, Arbre_Vis_Azimut.step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]
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2026-10-03 Démo PETG : pivots d'élévation imprimés Ø12 sur roulements 6801
    Seuls les arbres Ø5 des vis sans fin restent en acier. Les deux pivots
    d'élévation sont imprimés en PETG, en Ø12 au lieu de Ø8 pour tenir le
    couple de la roue, sur des 6801 (12 x 21 x 5) à la place des 608.
    Le cas réel (axes inox Ø8 sur 608) est inchangé.
    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
    [Bague_Arret_Moyeu.step, Chape.step, Chape.stl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]
2026-10-03 Roulements protégés : appuis sur la bonne bague, jamais sur la protection
    Tous les roulements sont protégés (ZZ conseillé, ou 2RS), modélisés avec
    leur flasque en retrait. Chaque pièce n'appuie que sur la bague qui tourne
    avec elle :
    - bras de la chape : épaulement Ø19,8 / Ø19,5 sur la bague extérieure des
    608 / 6801 (l'ancien Ø10 frottait sur la bague intérieure des 608) ;
    - chapeau : bossages Ø11,5 / Ø14,2 sur les bagues intérieures, qui règlent
    le jeu axial (plus de rondelles PTFE) ;
    - 6806 : collerette du moyeu et rondelle d'arrêt Ø33, épaulement du socle
    et alésage de la roue d'azimut Ø40 ;
    - 685 : lèvre de 1 mm sur chaque joue des paliers, épaulements Ø6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
    [Bague_Arret_Moyeu.step, Bague_Arret_Moyeu.stl, Chape.step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]
2026-10-03 Fixation du panneau sur les rails montable, contrôle d'échelle et de stabilité
    - Panneau : 4 vis M3x14 par-dessous à travers les bouts des rails (têtes
    noyées) et l'aile arrière du cadre, écrou M3 dans le cadre. Avant, les
    vis devaient être vissées de l'intérieur du cadre, derrière la vitre,
    et n'étaient pas modélisées. Trous Ø3,4 dans le cadre, vis et écrous
    ajoutés à l'assemblage.
    - Liste d'achats et README alignés sur le modèle : 6 x M3x8, 8 x M3x14,
    4 écrous M3 (le README et la liste ne donnaient pas le même compte).
    - Balayage de garde : les roulements de pivots sont exclus de la garde de
    la partie basculante (appui voulu des bossages, contrôlé à pa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
    [Cadre_Panneau.step, Ecrou_M3.step, Rail_Panneau.step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]
2026-10-03 PETG : trous horizontaux en goutte, éprouvette avec paroi de trous horizontaux
    Les perçages de précision imprimés à l'horizontale (logements des 6801
    dans les bras de la chape, des 685 dans les joues des paliers, alésages
    des pivots dans le chapeau, centrages des moteurs) sont en goutte dans le
    sens d'impression de chaque pièce : deux pans à 45° tronqués 0,6 mm
    au-dessus du cercle. Le haut d'un trou horizontal s'affaisse à
    l'impression ; la goutte s'imprime sans support et le roulement porte sur
    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
    [Chape.step, Chape.stl, Chapeau_U.step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]
2026-10-03 Panneau pesé à 1,16 kg : jambes à 33,0°, couples et bilan de dimensionnement
    - Masse mesurée du panneau (P["pan_masse"] = 1,16 kg) : le laminé est
    recalé pour que le panneau complet pèse cette masse (1,01 kg estimés
    avant).
    - Avec 150 g de plus au sommet, φ = 32,5° ne tenait plus l'exigence de
    stabilité (25,1° < 25,2°) : optimum à 33,0°. Jambes de 559 mm, pieds sur
    Ø749 mm, basculement à 25,4° dans le pire cas. Trépied régénéré,
    balayage de garde complet refait (2,0 mm / 1,0 mm, aucune interférence).
    - README : couples et marges recalculés, et nouveau bilan de
    dimensionnement (part du couple moteur utilisée, contraintes PETG,
    roulements, inertie, vite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
    [Bague_Blocage.step, Bride_Entretoise.step, Collier_Inferieur.step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]
2026-10-04 NEMA 11 réel (11HS18-0674S) : masse 180 g, vis M2,5x6, branchement
    - Moteur d'azimut : masse réelle 0,18 kg (0,14 avant), 6,8 Ω, taraudages
    de fixation de 2,5 mm modélisés : vis M2,5x6 au lieu de M2,5x8, qui
    auraient buté au fond des trous avant de serrer.
    - Optimum des jambes inchangé (33,0°, basculement 25,3° pour 25,1°
    exigés), aucune interférence, marges inchangées.
    - README : courant 0,9 A du NEMA 17 en version PETG rappelé dans les
    réglages, moteurs jamais alimentés en permanence (chauffe des supports
    PETG), couleurs des fils du NEMA 11.
    Claude-Session: https://claude.ai/code/session_016qGFaGRdDEyZRcESre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
    [Moteur_Azimut_NEMA11.step, Tete_Rotative_PETG.step, Tete_Rotative_VisSansFin.step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]
2026-10-04 NEMA 17 réel (Usongshine 17HS3401, 0,34 N·m) : cotes du plan, 0,6 A en PETG
    - Moteur d'élévation d'après son plan : 0,34 N·m à 1,0 A, axe Ø5 x 23,5,
    taraudages M3 de 4,5 mm (les M3x8 conviennent), connecteur JST PH
    6 broches de 16,2 mm. NEMA 11 : fils directs, sans connecteur.
    - Version PETG : courant réglé (amp_petg) pris en compte dans les couples.
    À 0,6 A, le moteur calé donne 2,97 N·m à la roue (dents vers 37 MPa) ;
    marges ×1,7 dehors (vent 10 m/s) et ×2,3 en intérieur. À 1,0 A il
    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
    [Moteur_Azimut_NEMA11.step, Moteur_Elevation_NEMA17.step, Tete_Rotative_PETG.step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]
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2026-10-08 Démo PETG sur le trépied Dexter : assemblage 3D, contrôles et stabilité
    - generate_demo_trepied.py : trépied photo Dexter modélisé d'après les
    photos (plateau à 600 mm du sol, pieds à 230 mm de l'axe, mesurés), tête
    PETG, panneau et capteur solaire vissés sur sa vis 1/4".
    - CAO/Demo_Terre_PETG/Demo_Trepied_Dexter.step et 4 rendus.
    - Aucune interférence ; garde de 33 mm entre le panneau et le plateau.
    - Stabilité calculée dans toutes les orientations : basculement à 8,6° de
    pente et vers 7,9 m/s de vent sans lest, 11,4 m/s avec 3 kg de lest.
    - README : section sur le trépied Dexter, consignes (lest, jambe au sud,
    rotule), fichiers et commandes.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
    [Demo_Trepied_Dexter.step]
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2026-10-12 README : cadence du suivi (correction de 0,5° toutes les 2 minutes, photodiodes + calcul)
    - § 17 : nouvelle partie « Cadence du suivi » : lecture des photodiodes et calcul toutes
    les 10 s, zone morte de 0,25°, correction de 0,5° qui place le panneau 0,25° en avance
    (une correction toutes les 2 minutes environ), moteurs coupés entre deux corrections,
    mouvement à 0,5°/s avec rampes (pas d'à-coup), retour vers l'est le soir, réglage
    pour une vidéo en accéléré ; pourquoi pas de suivi continu.
    - § 3 : zone morte harmonisée à 0,25° (0,022) ; cadence sur la Lune : une correction
    par heure.
    - § 2 : renvoi vers la cadence ; vitesse des corrections dans le tableau des vi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
2026-10-16 Plaque à pastilles compacte 7 × 9 cm et mini abaisseur 5 V
    - Implantation Fritzing réagencée : plaque de 24 × 30 trous au lieu de
    46 × 30, chaque pièce à côté de ce qu'elle dessert (borniers des
    moteurs sur les drivers, borniers des capteurs sur l'ADS1115, Heltec en
    bas, J1, U1 et X1 au bord droit), aucune pièce cachée sous un module.
    - Bords réels de la plaque et ses 4 trous de fixation ; vue rapprochée de
    la plaque dans docs/electronique/plaque_pastilles.png.
    - LM2596 remplacé par un mini abaisseur à sortie fixe 5,0 V ; le capteur
    Hall B1 est alimenté avant D1 (+5 V U1), le Heltec reçoit environ 4,7 V.
    - Borniers au pas de 2,54 mm pour les capteurs (X4 à X6) ;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
2026-10-27 Régulateur SOL10UC3 vissé sous la porte du boîtier
    - Implantation : le régulateur passe sous la porte (dessinée ouverte sous
    le boîtier, vue de l'intérieur) ; porte fermée, il vient au droit de la
    plaque et des wattmètres, jamais de la batterie, avec la zone à laisser
    libre. F1 sur la porte contre la borne LOAD ; boucle des 6 fils à la
    charnière.
    - Boîtier réagencé : batterie debout à droite de la plaque, F2 dans le
    couloir de câblage, wattmètres sous la plaque, S1 sur la paroi des
    presse-étoupes. Intérieur 196 × 120 mm (au lieu de 208 × 166), 120 mm
    de haut ; boîtier à porte sur charnières, opaque et clair.
    - README et liste d'achats : fixation étanch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
2026-10-27 Batterie couchée (70 mm dans la profondeur) : boîtier de 80 mm de profondeur
    - Implantation vue de face, porte ouverte : la batterie fait 100 × 88 mm,
    bornes sur sa face gauche (− au-dessus du +) dans le couloir de câblage,
    F2 sous elle. Intérieur 226 × 120 mm et 80 mm de profondeur (au lieu de
    196 × 120 et 120) : boîtier d'environ 250 × 150 × 100 mm.
    - Le régulateur de la porte (80 × 110 × 25 mm) reste devant la plaque et
    les wattmètres, jamais devant la batterie.
    - README, cartouche et liste d'achats : batterie étanche (AGM) couchée,
    jamais tête en bas.
    Claude-Session: https://claude.ai/code/session_016qG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
2026-10-28 Liste d'achats : plaque à pastilles 7 × 9 cm précisée (24 × 30 trous)
    Époxy FR4 1,6 mm, double face, trous métallisés, 4 trous de fixation ;
    mise en garde contre les 7 × 9 cm à 23 × 31 trous, qui n'ont pas la
    rangée du bas de l'implantation.
    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
2026-10-28 Liste d'achats : trous de fixation de la plaque dans la 2e rangée de chaque coin
    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
